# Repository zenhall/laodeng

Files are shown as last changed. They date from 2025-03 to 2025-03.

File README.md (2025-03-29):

# 老灯同学 - 多模态机器人台灯 🤖💡

> 一个集成了语音控制、姿态监测和智能照明的开源机器人台灯项目。

## ✨ 主要特点

### 🎯 语音指令控制
- 通过LLM实现自然语言理解
- 支持多种语音指令：
  - `老灯同学` - 抬头响应
  - `阅读模式` - 切换到阅读照明模式
  - `关灯` - 关闭照明并移动到休息位置

### 🕒 智能久坐提醒
- 基于视觉语言模型(VLM)的人体检测
- 智能计数系统：
  - 检测到连续久坐会触发不同级别的提醒
  - 通过LED灯光颜色变化直观显示久坐时长
  - 到达阈值时会执行摇头和闪烁等提醒动作

### 🎮 交互控制
- 支持手动拖动调节灯光位置
- 实时LED状态反馈

## 项目结构
```bash
.
├── 3D/                  # 3D打印模型文件
├── PCBA/                # 电路板设计文件     
├── esp32/
│   ├── combined_cam/        # ESP32主程序
│   │   └── combined_cam.ino # 下位机程序
│   └── wifi_stream/     # 视觉处理相关程序
│       └── wifi_stream.py
└── monitor_iat.py       # 语音控制程序
```

## 🛠️ 硬件要求

- XIAO ESP32-S3 SENSE开发板
- 转接扩展板
- 3D结构基于[SOARM100](https://github.com/huggingface/lerobot/blob/main/examples/10_use_so100.md)修改

## 📦 软件依赖

### 基础环境
- Python 3.8+
- pip 包管理器

### 主要依赖包
| 包名 | 用途 |
|---|---|
| OpenAI API | LLM接口 |
| OpenCV | 图像处理 |
| PyAudio | 音频处理 |
| Pillow | 图像处理 |
| NumPy | 数值计算 |
| Websocket-client | 网络通信 |

### 安装依赖
```bash
# 安装依赖
pip install -r requirements.txt
```

### 环境配置
1. 确保已安装 Python 3.8 或更高版本
2. 配置 OpenAI API：
   - 在 `monitor_iat.py` 和 `wifi_stream.py` 中设置你的LLM API key可于以下项目中获取免费额度：https://github.com/chatanywhere/GPT_API_free 
   - 在 `iat.py` 中设置你的IAT API key可注册科大讯飞开放平台获得免费额度
3. 配置网络：
   - 确保 ESP32 和运行程序的设备在同一网络下
   - 在代码中更新 ESP32 的 IP 地址

## 使用说明

### 语音控制模式
```bash
python monitor_iat.py
```

### 视觉处理模式
```bash
python esp32/wifi_stream/wifi_stream.py
```

## 📝 许可证

本项目采用 [MIT](LICENSE) 许可证。

## 🙏 致谢

- 感谢所有为本项目做出贡献的开发者
- 感谢shizhe的3D曲面模型设计

<p align="center">
  <a href="#top">返回顶部 ⬆️</a>
</p>

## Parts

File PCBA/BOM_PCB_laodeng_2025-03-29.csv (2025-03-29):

ID | Name | Designator | Footprint | Quantity | Manufacturer Part | Manufacturer | Supplier | Supplier Part | Price
1 | 10uF | C1,C5 | C0603 | 2
2 | 22uF | C2 | C0603 | 1
3 | 3.3nF | C3 | C0603 | 1
4 | 100nF | C4 | C0603 | 1
5 | 510kΩ | R1 | R0603 | 1
6 | 100kΩ | R2,R3 | R0603 | 2
7 | 1MΩ | R8 | R0603 | 1
8 | TPS82130SILR | U1 | USIP-8_L3.0-W2.8-P0.65-TL-EP | 1
9 | MAX98357AETE+T | U2 | TQFN-16_L3.0-W3.0-P0.50-BL-EP1.5 | 1
10 | KLJ-01304T-08R07W | U3 | BUZ-SMD_4P-L13.0-W13.0-P11.4-BL | 1
11 | WS2815C-2020-4P | U4,U5,U6,U7,U8,U9,U10,U11,U12,U13,U14,U15 | LED-SMD_4P-L2.2-W2.0-P1.00_WS2815C-2020-4P | 12
12 | 2.54 7P | U16,U17 | 单排母针-2.54MM-7P | 2
13 | ZX-XH2.54-3PWT | CN1,SERVO-SERIAL,IO | CONN-SMD_3P-P2.54-XH2.54-WT | 3

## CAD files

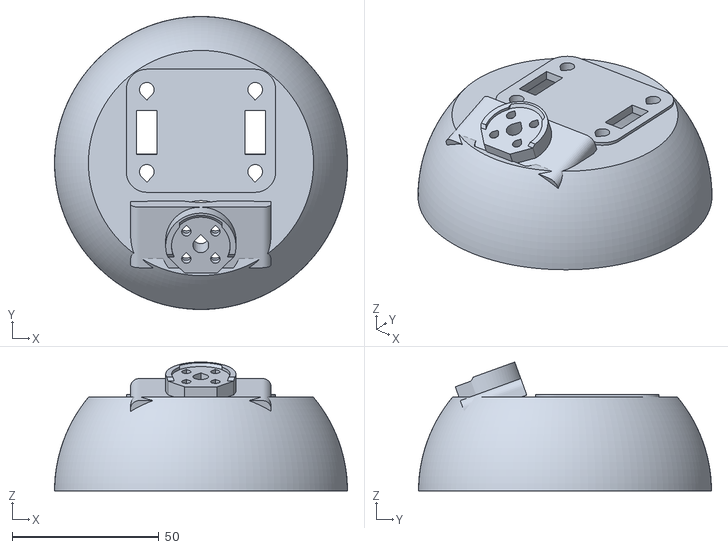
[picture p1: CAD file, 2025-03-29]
3D/laodeng/laodeng_dengzhao.stl
100.0 x 100.0 x 44.0

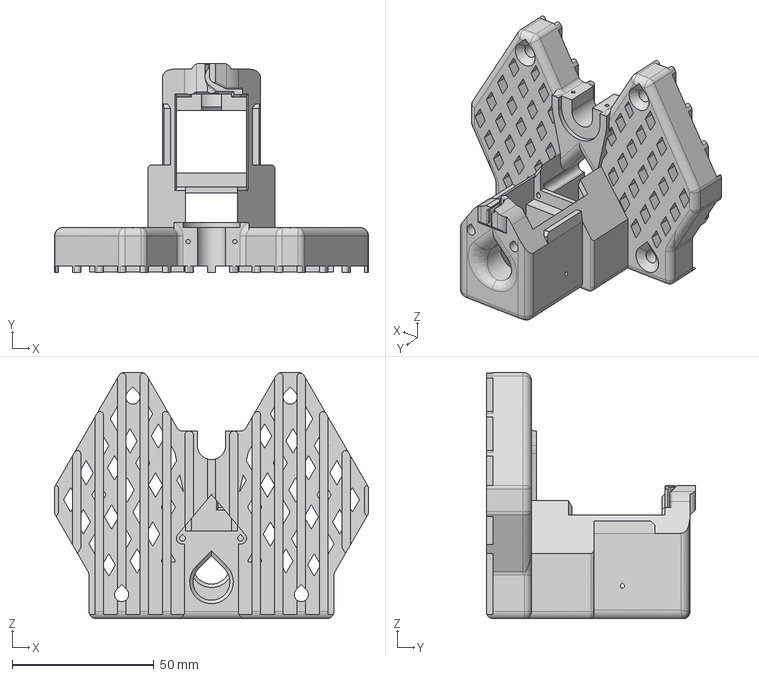
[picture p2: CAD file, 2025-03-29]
3D/SOARM100/Base_08q.step
110.9 x 74.0 x 87.0 mm

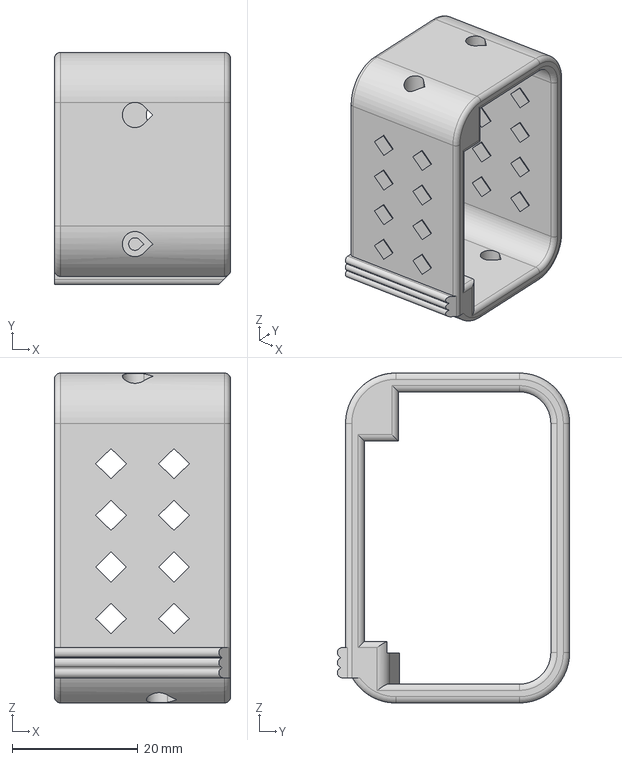
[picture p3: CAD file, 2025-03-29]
3D/SOARM100/SO_ARM100_08k.step
28.0 x 36.9 x 52.4 mm

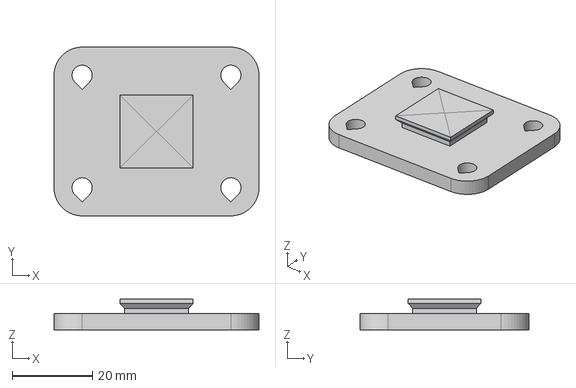
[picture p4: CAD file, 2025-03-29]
3D/SOARM100/WaveShare_Mounting_Plate_01d.step
51.0 x 42.0 x 7.60 mm

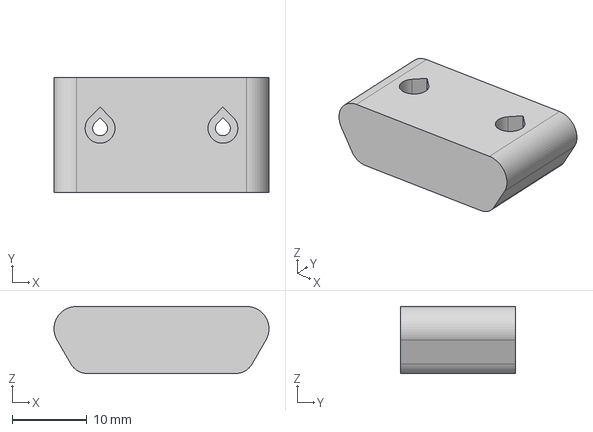
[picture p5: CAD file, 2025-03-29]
3D/SOARM100/Base_attachment.step
28.8 x 15.4 x 9.00 mm

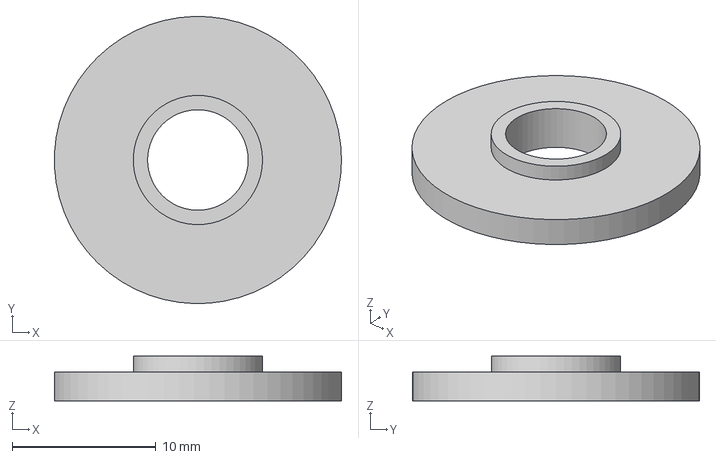
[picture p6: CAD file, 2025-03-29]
3D/SOARM100/Passive_Horn_01.step
20.0 x 20.0 x 3.10 mm

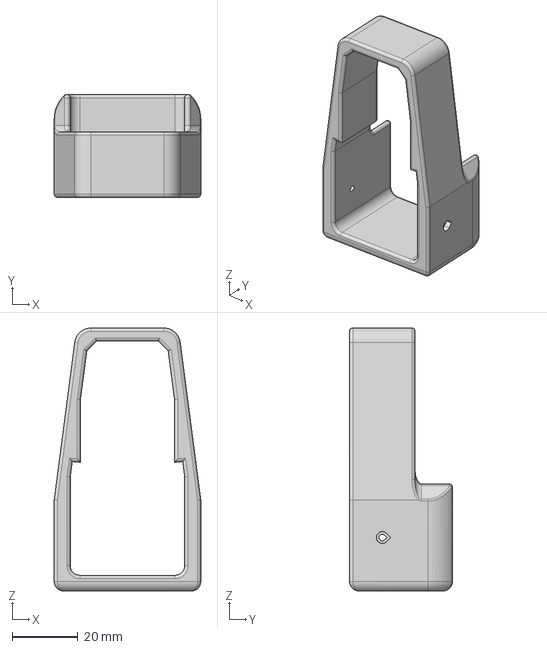
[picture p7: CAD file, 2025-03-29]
3D/SOARM100/Motor1_holder.step
44.7 x 31.4 x 80.2 mm

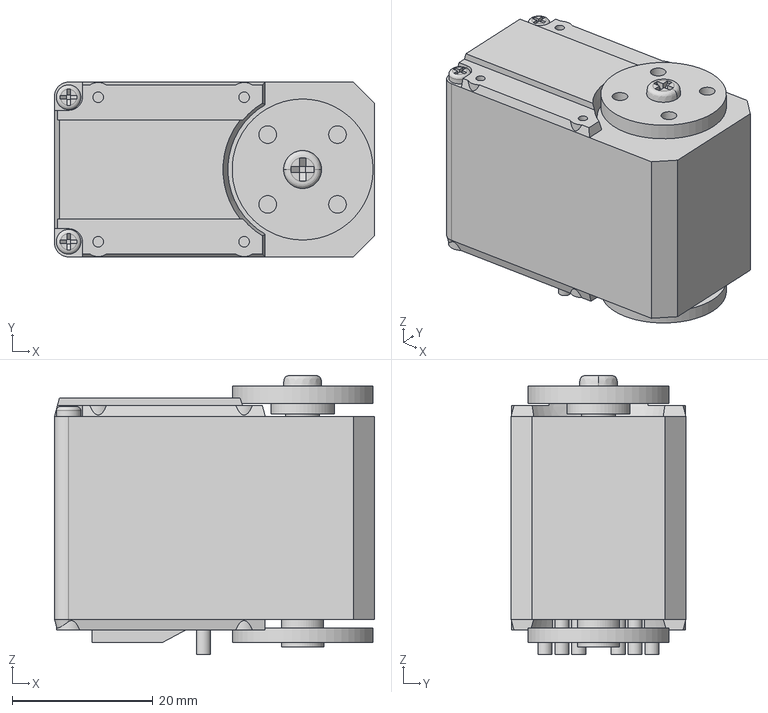
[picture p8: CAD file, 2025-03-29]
3D/SOARM100/STS3215_03a.step
45.4 x 24.8 x 39.6 mm

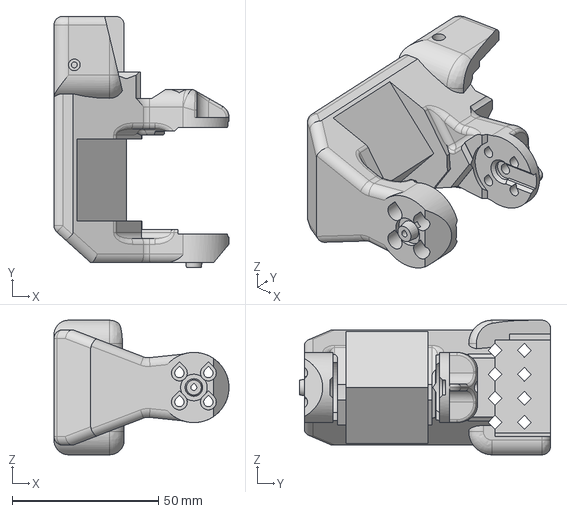
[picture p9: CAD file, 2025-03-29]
3D/SOARM100/Rotation_Pitch_08i.step
59.8 x 85.9 x 46.0 mm

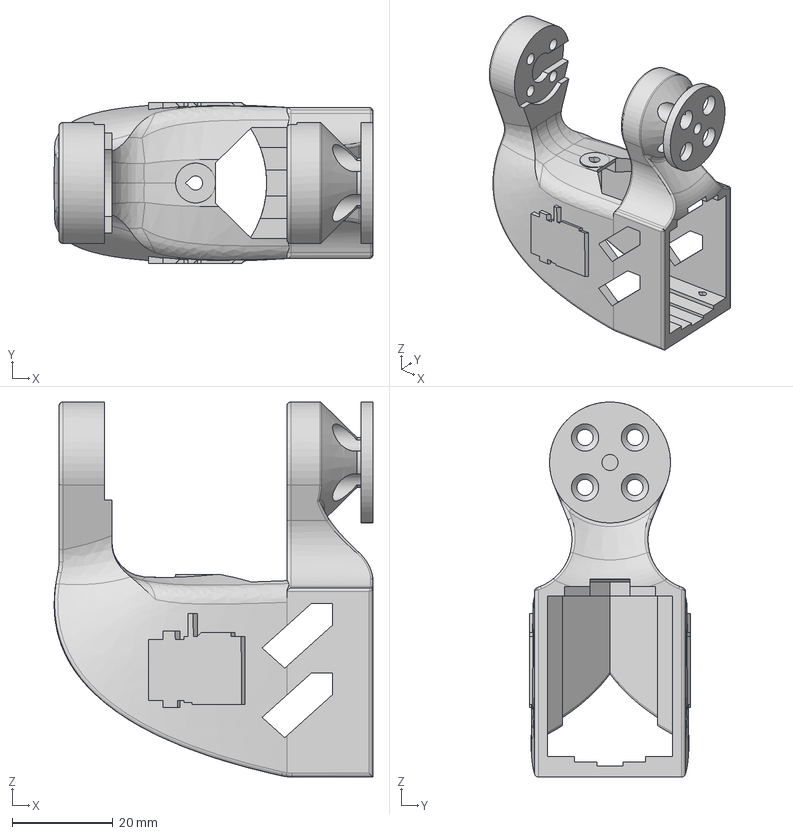
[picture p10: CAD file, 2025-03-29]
3D/SOARM100/Wrist_Roll_Pitch_08i.step
63.3 x 32.0 x 74.4 mm

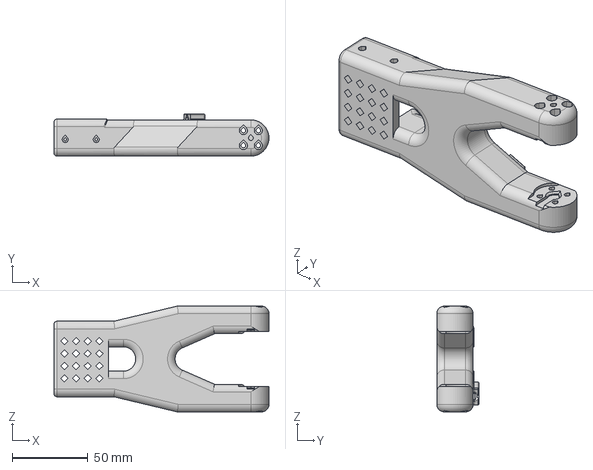
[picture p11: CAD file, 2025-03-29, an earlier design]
3D/SOARM100/SO_ARM100_08k (1).step
142.2 x 28.0 x 70.0 mm

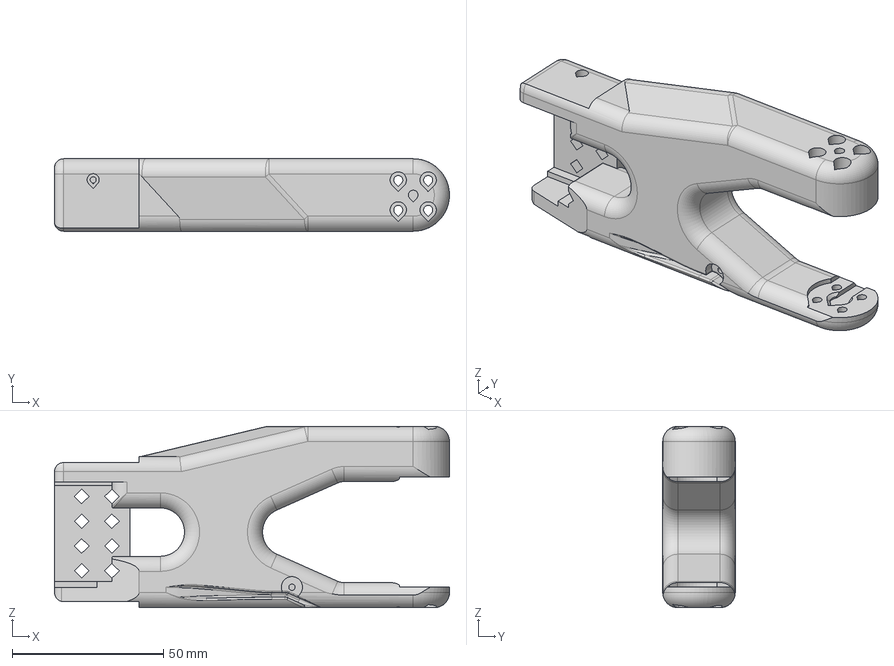
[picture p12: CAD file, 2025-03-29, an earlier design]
3D/SOARM100/SO_ARM100_08k (2).step
130.7 x 24.0 x 60.0 mm

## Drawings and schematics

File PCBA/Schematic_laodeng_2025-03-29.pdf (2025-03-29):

## 12v-5V power

## SOUND

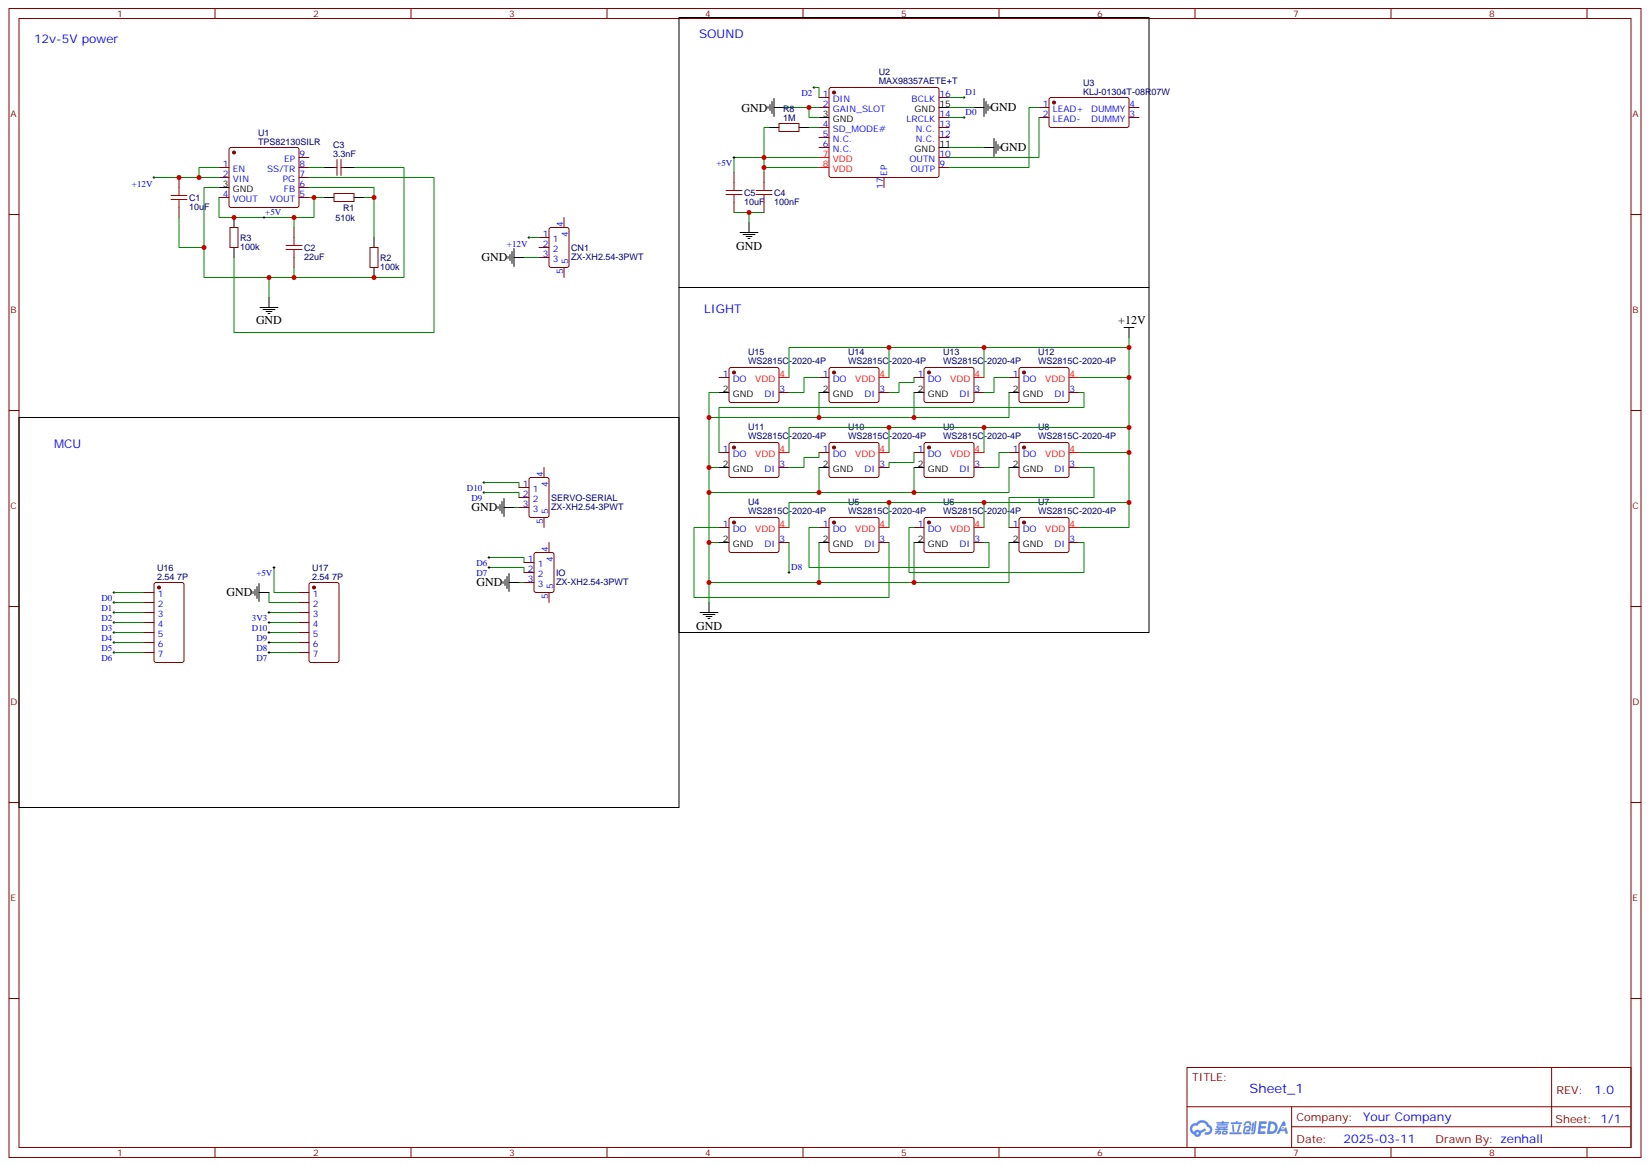
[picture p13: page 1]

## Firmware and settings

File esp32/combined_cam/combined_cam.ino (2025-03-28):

#include <Adafruit_NeoPixel.h>
#include <ESP_I2S.h>
#include <WiFi.h>
#include <SCServo.h>
#include <ArduinoJson.h>
#include "esp_camera.h"
#define CAMERA_MODEL_XIAO_ESP32S3 // Has PSRAM
#include "camera_pins.h"

// FreeRTOS相关
TaskHandle_t wifiCommandTaskHandle;
TaskHandle_t micTaskHandle;
TaskHandle_t servoTaskHandle;
TaskHandle_t statusTaskHandle;
TaskHandle_t cameraTaskHandle;

// WiFi设置
const char* ssid = "2nd-curv";
const char* password = "xbotpark";
const char* host = "192.168.5.24";
const uint16_t commandPort = 8080;  // 命令端口
const uint16_t audioPort = 8081;    // 音频数据端口
const uint16_t statusPort = 8082;   // 状态反馈端口

// 网络客户端
WiFiClient commandClient;    // 接收命令
WiFiClient audioClient;      // 发送音频
WiFiClient statusClient;     // 发送状态

// NeoPixel设置
#define PIN        7
#define NUMPIXELS 10
Adafruit_NeoPixel pixels(NUMPIXELS, PIN, NEO_GRB + NEO_KHZ800);

// I2S和音频设置
I2SClass I2S;
const int BUFFER_SIZE = 1024;
char audioBuffer[BUFFER_SIZE];
const int GAIN = 20;

// 舵机设置
#define S_RXD 8
#define S_TXD 9
SMS_STS st;
byte ID[5];
u16 Speed[5];
byte ACC[5];

// JSON文档
StaticJsonDocument<200> cmdDoc;
StaticJsonDocument<500> statusDoc;

// 添加TCP服务器对象
WiFiServer ServerPort(1234);

// 添加HTTP流媒体服务器相关声明
void startCameraServer();
void setupLedFlash(int pin);

// 处理接收到的命令
void handleCommand(const char* command) {
  DeserializationError error = deserializeJson(cmdDoc, command);
  if (error) {
    Serial.println("解析JSON失败");
    return;
  }

  const char* type = cmdDoc["type"];
  
  if (strcmp(type, "servo") == 0) {
    // 舵机控制命令格式：
    // {"type":"servo","positions":[1000,2000,3000,4000,5000],"speeds":[3400,3400,3400,3400,3400]}
    JsonArray positions = cmdDoc["positions"];
    JsonArray speeds = cmdDoc["speeds"];
    
    for(int i = 0; i < 5; i++) {
      Speed[i] = speeds[i] | 3400;  // 如果未指定则使用默认值3400
      ACC[i] = 50;
    }
    
    s16 newPositions[5];
    for(int i = 0; i < 5; i++) {
      newPositions[i] = positions[i];
    }
    
    st.SyncWritePosEx(ID, 5, newPositions, Speed, ACC);
  }
  else if (strcmp(type, "led") == 0) {
    // LED控制命令格式：
    // {"type":"led","index":0,"r":255,"g":0,"b":0}
    int index = cmdDoc["index"];
    int r = cmdDoc["r"];
    int g = cmdDoc["g"];
    int b = cmdDoc["b"];
    
    if (index >= 0 && index < NUMPIXELS) {
      pixels.setPixelColor(index, pixels.Color(r, g, b));
      pixels.show();
    }
    else if (index == -1) {  // -1表示设置所有LED
      for(int i = 0; i < NUMPIXELS; i++) {
        pixels.setPixelColor(i, pixels.Color(r, g, b));
      }
      pixels.show();
    }
  }
}

// WiFi命令处理任务
void wifiCommandTask(void *parameter) {
  Serial.println("命令任务已启动");
  char commandBuffer[256];
  int bufferIndex = 0;
  
  while(1) {
    if (!commandClient.connected()) {
      commandClient.stop();
      if (commandClient.connect(host, commandPort)) {
        Serial.println("命令通道已连接");
      } else {
        vTaskDelay(pdMS_TO_TICKS(1000));
        continue;
      }
    }

    while (commandClient.available()) {
      char c = commandClient.read();
      if (c == '\n') {
        commandBuffer[bufferIndex] = '\0';
        handleCommand(commandBuffer);
        bufferIndex = 0;
      } else if (bufferIndex < 255) {
        commandBuffer[bufferIndex++] = c;
      }
    }
    
    vTaskDelay(pdMS_TO_TICKS(10));
  }
}

// 麦克风采集任务
void micTask(void *parameter) {
  Serial.println("麦克风任务已启动");
  while(1) {
    if (!audioClient.connected()) {
      audioClient.stop();
      if (audioClient.connect(host, audioPort)) {
        Serial.println("音频通道已连接");
      } else {
        vTaskDelay(pdMS_TO_TICKS(1000));
        continue;
      }
    }

    size_t bytes_read = I2S.readBytes(audioBuffer, BUFFER_SIZE);
    if (bytes_read > 0) {
      int16_t* samples = (int16_t*)audioBuffer;
      int num_samples = bytes_read / 2;
      
      for (int i = 0; i < num_samples; i++) {
        int32_t amplified = samples[i] * GAIN;
        if (amplified > 32767) amplified = 32767;
        if (amplified < -32768) amplified = -32768;
        samples[i] = (int16_t)amplified;
      }
      
      audioClient.write(audioBuffer, bytes_read);
    }
    vTaskDelay(pdMS_TO_TICKS(5));
  }
}

// 状态反馈任务
void statusTask(void *parameter) {
  Serial.println("状态任务已启动");
  while(1) {
    if (!statusClient.connected()) {
      statusClient.stop();
      if (statusClient.connect(host, statusPort)) {
        Serial.println("状态通道已连接");
      } else {
        vTaskDelay(pdMS_TO_TICKS(1000));
        continue;
      }
    }

    // 构建状态JSON
    statusDoc.clear();
    JsonArray servoPositions = statusDoc.createNestedArray("servo_positions");
    JsonArray ledStates = statusDoc.createNestedArray("led_states");

    // 读取舵机位置
    for(int id = 1; id <= 5; id++) {
      int pos = st.ReadPos(id);
      servoPositions.add(pos);
    }

    // 读取LED状态
    for(int i = 0; i < NUMPIXELS; i++) {
      uint32_t color = pixels.getPixelColor(i);
      JsonObject led = ledStates.createNestedObject();
      led["index"] = i;
      led["r"] = (color >> 16) & 0xFF;
      led["g"] = (color >> 8) & 0xFF;
      led["b"] = color & 0xFF;
    }

    // 发送状态
    String statusString;
    serializeJson(statusDoc, statusString);
    statusString += "\n";  // 添加换行符作为消息分隔
    statusClient.print(statusString);

    vTaskDelay(pdMS_TO_TICKS(100));  // 每100ms发送一次状态
  }
}

// 添加摄像头任务处理函数
void cameraTask(void *parameter) {
  Serial.println("摄像头任务已启动");
  while(1) {
    WiFiClient client = ServerPort.available();
    if (client) {
      Serial.println("新客户端连接");
      
      while (client.connected()) {
        if (client.available()) {
          // 读取检测结果
          String data = client.readStringUntil('\n');
          
          // 解析并显示每个检测结果
          Serial.println("检测结果:");
          
          // 按分号分割字符串
          int prevIndex = 0;
          int colonIndex = -1;
          
          while ((colonIndex = data.indexOf(';', prevIndex)) != -1) {
            String detection = data.substring(prevIndex, colonIndex);
            Serial.println(detection);
            prevIndex = colonIndex + 1;
          }
          
          if (prevIndex < data.length()) {
            Serial.println(data.substring(prevIndex));
          }
          
          client.println("Data received");
        }
      }
      
      client.stop();
      Serial.println("客户端断开连接");
    }
    vTaskDelay(pdMS_TO_TICKS(10));
  }
}

void setup() {
  Serial.begin(115200);
  Serial.println("程序启动");
  
  camera_config_t config;
  config.ledc_channel = LEDC_CHANNEL_0;
  config.ledc_timer = LEDC_TIMER_0;
  config.pin_d0 = Y2_GPIO_NUM;
  config.pin_d1 = Y3_GPIO_NUM;
  config.pin_d2 = Y4_GPIO_NUM;
  config.pin_d3 = Y5_GPIO_NUM;
  config.pin_d4 = Y6_GPIO_NUM;
  config.pin_d5 = Y7_GPIO_NUM;
  config.pin_d6 = Y8_GPIO_NUM;
  config.pin_d7 = Y9_GPIO_NUM;
  config.pin_xclk = XCLK_GPIO_NUM;
  config.pin_pclk = PCLK_GPIO_NUM;
  config.pin_vsync = VSYNC_GPIO_NUM;
  config.pin_href = HREF_GPIO_NUM;
  config.pin_sccb_sda = SIOD_GPIO_NUM;
  config.pin_sccb_scl = SIOC_GPIO_NUM;
  config.pin_pwdn = PWDN_GPIO_NUM;
  config.pin_reset = RESET_GPIO_NUM;
  config.xclk_freq_hz = 20000000;
  config.frame_size = FRAMESIZE_UXGA;  // 改为UXGA
  config.pixel_format = PIXFORMAT_JPEG;
  config.grab_mode = CAMERA_GRAB_WHEN_EMPTY;
  config.fb_location = CAMERA_FB_IN_PSRAM;
  config.jpeg_quality = 12;
  config.fb_count = 1;
  
  // 添加PSRAM检查和相应配置
  if (config.pixel_format == PIXFORMAT_JPEG) {
    if (psramFound()) {
      config.jpeg_quality = 10;
      config.fb_count = 2;
      config.grab_mode = CAMERA_GRAB_LATEST;
    } else {
      // 如果没有PSRAM，限制帧大小
      config.frame_size = FRAMESIZE_SVGA;
      config.fb_location = CAMERA_FB_IN_DRAM;
    }
  }

  esp_err_t err = esp_camera_init(&config);
  if (err != ESP_OK) {
    Serial.printf("摄像头初始化失败，错误代码: 0x%x\n", err);
    return;
  }

  // 初始化后配置传感器
  sensor_t * s = esp_camera_sensor_get();
  if (s->id.PID == OV3660_PID) {
    s->set_vflip(s, 1);
    s->set_brightness(s, 1);
    s->set_saturation(s, -2);
  }
  // 降低帧大小以获得更高的初始帧率
  if (config.pixel_format == PIXFORMAT_JPEG) {
    s->set_framesize(s, FRAMESIZE_QVGA);
  }

  // 初始化LED
  pixels.begin();
  pixels.clear();
  pixels.show();
  Serial.println("LED初始化完成");  // 添加LED初始化信息
  
  // 初始化I2S
  I2S.setPinsPdmRx(42, 41);
  if (!I2S.begin(I2S_MODE_PDM_RX, 16000, I2S_DATA_BIT_WIDTH_16BIT, I2S_SLOT_MODE_MONO)) {
    Serial.println("I2S初始化失败！");
    while (1);
  }
  Serial.println("I2S初始化成功");  // 添加I2S初始化信息
  
  // 初始化WiFi
  Serial.print("正在连接WiFi");
  WiFi.begin(ssid, password);
  WiFi.setSleep(false);  // 禁用WiFi睡眠模式以提高性能
  
  while (WiFi.status() != WL_CONNECTED) {
    delay(500);
    Serial.print(".");
  }
  Serial.println("\nWiFi已连接");
  Serial.print("IP地址: ");
  Serial.println(WiFi.localIP());

  // 启动摄像头HTTP服务器
  startCameraServer();
  Serial.print("摄像头服务器就绪! 使用 'http://");
  Serial.print(WiFi.localIP());
  Serial.println("/stream' 进行连接");  // 添加/stream路径
  
  // 初始化舵机通信
  Serial1.begin(1000000, SERIAL_8N1, S_RXD, S_TXD);
  st.pSerial = &Serial1;
  Serial.println("舵机通信初始化完成");  // 添加舵机初始化信息
  
  // 初始化舵机参数
  for(int i = 0; i < 5; i++) {
    ID[i] = i + 1;
    Speed[i] = 3400;
    ACC[i] = 50;
  }

  // 启动TCP服务器
  ServerPort.begin();
  Serial.println("TCP服务器已启动");
  
  // 创建任务
  Serial.println("开始创建任务");  // 添加任务创建信息
  xTaskCreate(wifiCommandTask, "Command Task", 8192, NULL, 2, &wifiCommandTaskHandle);  // 增加堆栈大小
  xTaskCreate(micTask, "Mic Task", 8192, NULL, 2, &micTaskHandle);
  xTaskCreate(statusTask, "Status Task", 8192, NULL, 1, &statusTaskHandle);
  xTaskCreate(cameraTask, "Camera Task", 8192, NULL, 1, &cameraTaskHandle);
  Serial.println("所有任务创建完成");  // 添加任务创建完成信息
}

void loop() {
  vTaskDelay(pdMS_TO_TICKS(1000));
} 

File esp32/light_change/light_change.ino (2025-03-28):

// NeoPixel Ring simple sketch (c) 2013 Shae Erisson
// Released under the GPLv3 license to match the rest of the
// Adafruit NeoPixel library

#include <Adafruit_NeoPixel.h>
#ifdef __AVR__
 #include <avr/power.h> // Required for 16 MHz Adafruit Trinket
#endif

// Which pin on the Arduino is connected to the NeoPixels?
#define PIN        7 // On Trinket or Gemma, suggest changing this to 1

// How many NeoPixels are attached to the Arduino?
#define NUMPIXELS 10 // Popular NeoPixel ring size

// When setting up the NeoPixel library, we tell it how many pixels,
// and which pin to use to send signals. Note that for older NeoPixel
// strips you might need to change the third parameter -- see the
// strandtest example for more information on possible values.
Adafruit_NeoPixel pixels(NUMPIXELS, PIN, NEO_GRB + NEO_KHZ800);

#define DELAYVAL 500 // Time (in milliseconds) to pause between pixels

// 添加舵机控制所需的头文件和定义
#define S_RXD 8
#define S_TXD 9
#include <SCServo.h>

SMS_STS sms_sts;

// 定义舵机位置范围
#define MIN_POS 1800
#define MAX_POS 2200

void setup() {
  // These lines are specifically to support the Adafruit Trinket 5V 16 MHz.
  // Any other board, you can remove this part (but no harm leaving it):
#if defined(__AVR_ATtiny85__) && (F_CPU == 16000000)
  clock_prescale_set(clock_div_1);
#endif
  // END of Trinket-specific code.

  Serial1.begin(1000000, SERIAL_8N1, S_RXD, S_TXD);
  Serial.begin(115200);
  sms_sts.pSerial = &Serial1;
  pixels.begin();
  delay(1000);
}

void loop() {
  // 读取三个舵机的位置并映射到RGB值
  int r = map(constrain(sms_sts.ReadPos(1), MIN_POS, MAX_POS), MIN_POS, MAX_POS, 0, 255);
  int g = map(constrain(sms_sts.ReadPos(2), MIN_POS, MAX_POS), MIN_POS, MAX_POS, 0, 255);
  int b = map(constrain(sms_sts.ReadPos(3), MIN_POS, MAX_POS), MIN_POS, MAX_POS, 0, 255);
  
  // 如果读取失败，使用默认值0
  r = (r == -1) ? 0 : r;
  g = (g == -1) ? 0 : g;
  b = (b == -1) ? 0 : b;

  // 设置所有像素的颜色
  for(int i=0; i<NUMPIXELS; i++) {
    pixels.setPixelColor(i, pixels.Color(r, g, b));
  }
  
  pixels.show();
  delay(50); // 降低刷新延迟以获得更流畅的效果
}

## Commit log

2025-03-28 human_detec_with_servo
    添加小狗摇头和警告闪烁
2025-03-29 add 3D&PCBA
    [BOM_PCB_laodeng_2025-03-29.csv, Base_08q.step, Base_attachment.step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]
2025-03-29 增加README
